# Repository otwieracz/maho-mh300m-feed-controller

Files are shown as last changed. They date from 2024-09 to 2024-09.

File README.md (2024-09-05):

# MAHO MH300M Feedrate Controller

## 1. Introduction

### 1.1 Purpose

The MH300M Feedrate Controller is designed to precisely align the panel readings for feed control on the MAHO MH300M milling machine with the voltage output for the tachogenerator. This ensures that the machine operates with accurate and reliable feed rates after the original BBbC LE 10 b-E driver was replaced with a Parker 512C driver.

### 1.2 Overview

This device is retrofitted into the control box of the MAHO MH300M, requiring no changes to the existing wiring. It connects to the Parker 512C driver, the machine's potentiometer, and the control panel's RAPID and CREEP (1/100) buttons. The device converts arbitrary potentiometer values into a calibrated voltage output, ensuring that the machine's feed rates are consistent and accurate.

### 1.3 MAHO MH300M Control Panel

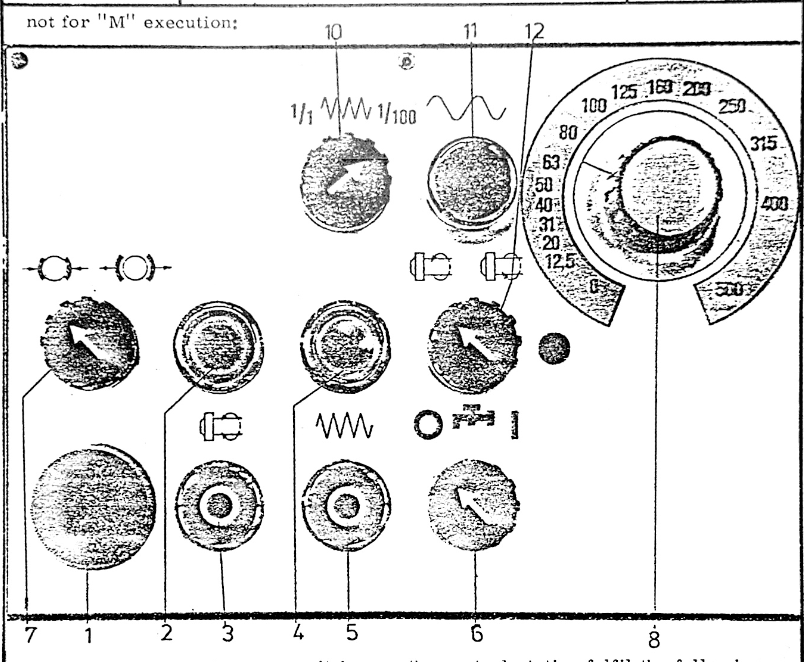
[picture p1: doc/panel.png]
MH300M Control panel


10. Creep feed rate switch (1/1 - 1/100). *Note: MAHO MH300M Feedrate Controller reduces the feed rate by a factor of 10 instead of 100 when in Creep Mode.*
11. Rapid feed rate switch.
12. Feedrate potentiometer.

## 2. Device Components and Connections

### 2.1 Connectors

The device has the following connectors:

- **512C Connector**: 
  - +10V Reference (maximum 5mA)
  - Analog Setpoint (output from the device)
  - Ground (GND)
- **Potentiometer Connector**: Connects to the machine's potentiometer.
- **RAPID and CREEP Button Connectors**: Connects to the control panel's RAPID and CREEP (1/100) buttons.
- **Clear EEPROM Button**: Used to reset the device's configuration stored in EEPROM.

### 2.2 LED Indicator

The device includes an LED indicator used to convey various status messages during setup and operation. The LED blinks in specific patterns to communicate different messages.

## 3. Configuration and Calibration

### 3.1 Initial Setup

Upon installation, the device requires calibration to match the feed rates of the milling machine with the appropriate voltage output. This calibration process is stored in the device's EEPROM, ensuring that the settings persist even after power cycles.

### 3.2 Clearing EEPROM

If you need to reset the device to its default configuration, press and hold the **Clear EEPROM** button while powering on the device. This will erase all stored settings and reset the device to its factory state.

**Note:** Clearing the EEPROM will require recalibration.

### 3.3 Calibration Procedures

Calibration is done in two main steps: configuring the digital potentiometer and setting the ADC steps.

#### 3.3.1 Digital Potentiometer Calibration

1. **Minimum Feed Rate Calibration**: 
   - The **Minimum Feed Rate** is the lowest feed rate at which the milling machine can operate stably. This feed rate is crucial as it ensures that the machine can perform slow movements without stalling, particularly under heavy loads.
   - To accurately determine the minimum feed rate, it's recommended to run all axes simultaneously, especially the Z-axis moving upward, as this simulates the heaviest load.
   - The device will enter the calibration mode for the minimum feed rate (in mm/min).
   - The LED will blink a long-short pattern (`-.`).
   - The device reads the analog input for 30 seconds to determine the minimum digital potentiometer value necessary to maintain stable operation.

2. **500 mm/min Feed Rate Calibration**:
   - The 500 mm/min feed rate serves as a key reference point. This feed rate corresponds to a voltage output of **4.16V** at the terminals of the Parker 512C.
   - The LED will blink a short-long pattern (`.-`).
   - To accurately measure this, connect a voltmeter to the 512C terminals to account for any voltage drop between the control box and the driver.
   - The device adjusts the potentiometer until the voltmeter reads exactly 4.16V, ensuring that the machine's feed rate is precisely 500 mm/min.

#### 3.3.2 ADC Steps Calibration

The device divides the feed rate range into 16 steps, each representing a specific feed rate.

1. **Step Calibration**:
   - For each step, the device reads the analog input for 5.5 seconds.
   - The LED will blink a long-long pattern (`--`) during each step.
   - For each step, set the potentiometer `10` on control panel to the corresponding feed rate (0, 12.5, 20, 31, 40, 50, 63, 80, 100, 125, 160, 200, 250, 315, 400, 500 mm/min).
   - The device will automatically store the ADC value corresponding to each feed rate in the EEPROM.

#### 3.3.3 EEPROM Storage

Once calibration is complete, the device will store the configuration in EEPROM, indicated by two short blinks (`..`). The device will then use this configuration to convert potentiometer values into the appropriate voltage output.

### 3.4 Manual Calibration and Monitoring via UART

#### 3.4.1 Overview

The UART interface is the primary method for monitoring and configuring the MH300M Feedrate Controller. This interface allows you to observe real-time status messages during the calibration process and verify the configuration settings. You can use any UART-capable device, such as a USB-to-UART adapter or a device like the Flipper Zero, to connect to the controller and monitor the serial output.

#### 3.4.2 Setting Up UART Communication

To begin using UART communication:

1. **Connect the Device**:
   - Connect the device's UART pins to your computer using a USB-to-UART adapter or to a handheld UART interface like the Flipper Zero.
   - Ensure the connection uses the correct UART pins (TX, RX, GND).

2. **Open a Serial Terminal**:
   - Open a serial terminal program on your computer (such as PuTTY, Tera Term, or the Arduino IDE's Serial Monitor).
   - Set the baud rate to **9600**.
   - Configure the terminal for **8 data bits, no parity, and 1 stop bit** (8N1).

3. **Start the Device**:
   - Power on the device. The serial terminal will begin displaying messages as the device goes through its initialization and calibration process.

#### 3.4.3 Calibration Process and UART Messages

The calibration process involves several steps, each of which is communicated via the UART interface. Below is a detailed breakdown of the calibration process, along with the messages you will see in the UART terminal.

1. **Initialization**:
   - **Starting Message**:
     - **UART Message**: `starting`
     - Description: Indicates that the device has powered on and is beginning the setup process.
   - **Button Setup**:
     - **UART Message**: `setting up buttons`
     - Description: The device configures the input pins for the RAPID, CREEP, and CLEAR EEPROM buttons.

2. **Configuration Reading**:
   - **Valid Configuration**:
     - **UART Message**: `valid config`
     - Description: Indicates that the device successfully read a valid configuration from the EEPROM.
   - **Invalid Configuration**:
     - **UART Message**: `invalid configuration`
     - Description: The configuration in the EEPROM is either missing or corrupt, triggering the initialization of a new calibration process.

3. **Calibration Steps**:
   - **Digital Potentiometer Minimum Calibration**:
     - **UART Message**: `initializing configuration`
     - Description: The device begins the calibration process.
     - **UART Message**: `config.digipot_min: <value>`
     - Description: The device determines and displays the minimum digital potentiometer value required for stable operation.
   - **Digital Potentiometer 500 mm/min Calibration**:
     - **UART Message**: `config.digipot_500: <value>`
     - Description: The device calculates and displays the digital potentiometer value corresponding to a 500 mm/min feed rate.
   - **ADC Setpoint Calibration**:
     - **UART Message**: `config.feed_<feed_rate>: <adc_value>`
     - Description: For each step in the feed rate table, the device reads and displays the corresponding ADC value. This process repeats for each of the 16 predefined steps.
   - **Completion Message**:
     - **UART Message**: `initialization complete`
     - Description: Indicates that the calibration process has finished successfully, and the configuration has been stored in the EEPROM.

#### 3.4.4 Operation Monitoring via UART

During normal operation, the UART interface continues to output real-time status messages, allowing you to monitor the device's performance:

- **Feed Rate and Voltage Output**:
  - **UART Message**: `fr: <feedrate>mm/min / <voltage>V`
  - Description: Displays the current feed rate in mm/min and the corresponding voltage output to the Parker 512C.

#### 3.4.5 Troubleshooting via UART

Use the UART messages to diagnose issues:

- If the device repeatedly outputs `invalid configuration`, ensure that the EEPROM is not corrupted or repeatedly reset.
- Monitor the feed rate and voltage messages to verify that the device operates as expected under different conditions (e.g., with RAPID or CREEP buttons pressed).

### 3.4.6 Flowchart of the Calibration Process with UART Monitoring

```mermaid
graph TD
    A[Power On] --> B{Clear EEPROM Button Pressed?}
    B -- Yes --> C[Clear EEPROM and Reset Configuration]
    B -- No --> D[Read Configuration from EEPROM]
    D -- Invalid --> E[Initialize Calibration]
    E --> F[Calibrate Digipot Min]
    F --> G[Calibrate Digipot 500 mm/min]
    G --> H[Calibrate ADC Setpoints]
    H --> I[Save Configuration to EEPROM]
    D -- Valid --> J[Start Operation]
    I --> J
    J --> K[Monitor Potentiometer Values]
    K --> L[Calculate Feedrate]
    L --> M[Convert Feedrate to Digipot Value]
    M --> N[Output Voltage to 512C]
```
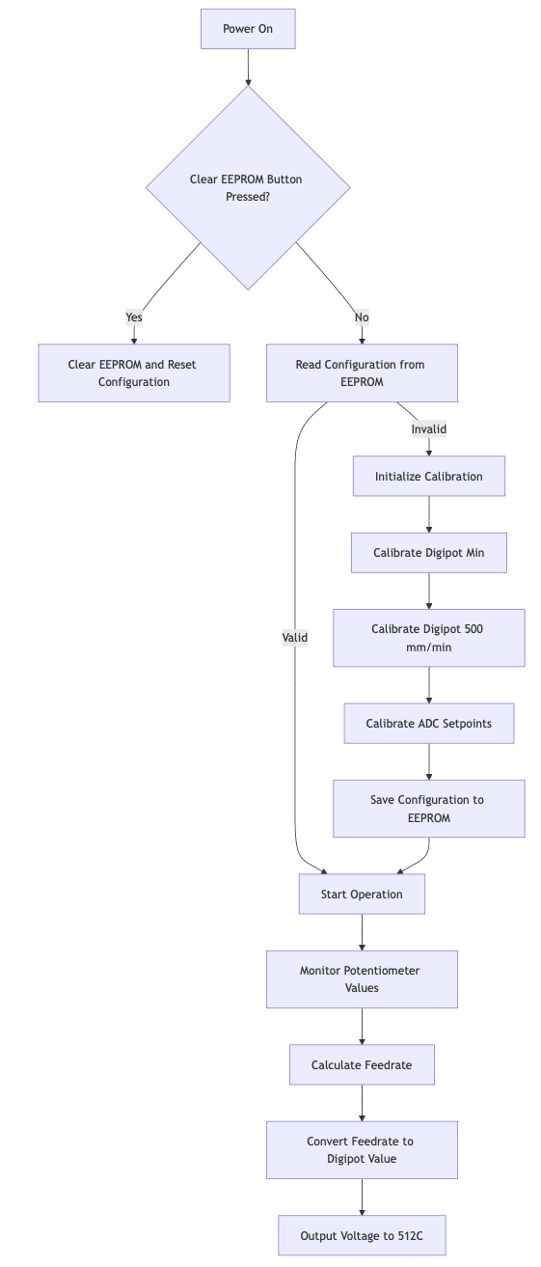
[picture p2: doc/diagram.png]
diagram


## 4. Operation

### 4.1 Normal Operation

Once configured, the device operates automatically, continuously converting the potentiometer's analog signal into a precise voltage output that drives the tachogenerator. This output is based on the calibrated settings stored in EEPROM.

### 4.2 Button Functions

- **RAPID Button**: When pressed, the feed rate is set to 1200 mm/min, overriding the potentiometer setting.
- **CREEP Button**: When pressed, the feed rate is reduced by a factor of 10.

### 4.3 Power Saving Mode

The device enters a low-power state between readings to conserve energy. This does not affect the device's performance but ensures it operates efficiently.

## 5. Maintenance and Troubleshooting

### 5.1 Regular Maintenance

The device requires minimal maintenance. Periodically check the connectors and wiring to ensure they are secure and free of damage.

### 5.2 Troubleshooting

- **No Output Voltage**: Verify that the device is receiving power and that the potentiometer is functioning correctly.
- **Incorrect Feed Rate**: Re-run the calibration procedure to ensure the settings are accurate.
- **LED Indicator Not Blinking**: Check the LED connections and ensure the device is powered on.

## 6. Technical Specifications

- **Input Voltage**: 10V from the Parker 512C
- **Analog Setpoint Output Range**: 0-10V
- **Maximum Current Draw**: 5mA from the 10V reference
- **EEPROM Storage**: Non-volatile memory storing calibration settings
- **Power Saving Mode**: Automatic, with 250ms sleep cycles

## 7. Safety Information

- Ensure all connections are secure before powering on the device.
- Do not attempt to modify the device's hardware.
- Use the device only for its intended purpose with the MAHO MH300M milling machine.

## Chapter 8: Programming the MH300M Feedrate Controller

### 8.1 Overview

Programming the MH300M Feedrate Controller involves configuring the microcontroller, setting fuse bits, and uploading the firmware. This chapter provides general guidelines on how to perform these tasks using standard AVR/Arduino practices.

### 8.2 Fuse Settings

Fuse settings are crucial for defining how the microcontroller operates at a hardware level. The fuses should be set to ensure the following:

- **Clock Source**: The microcontroller should use the internal oscillator with a specific clock divider to achieve the desired operating frequency (e.g., 1 MHz).
- **Bootloader Settings**: The fuses should be configured to allow the microcontroller to use a bootloader, if applicable.
- **EEPROM Retention**: Ensure that the EEPROM data is preserved during a chip erase.
- **Brown-Out Detection**: Configure the Brown-Out Detection (BOD) settings according to the requirements, or disable it if not needed.

These settings are typically configured using low, high, and extended fuse bits. Proper fuse settings ensure that the device runs at the correct speed, retains necessary data, and operates reliably under different power conditions.

### 8.3 Build Configuration

When building the firmware for the MH300M Feedrate Controller, the following flags and settings should be considered:

- **Microcontroller Type**: Ensure that the target microcontroller (e.g., ATmega328P) is correctly specified in the build configuration.
- **CPU Frequency**: Set the CPU frequency to match the hardware configuration (e.g., 1 MHz).
- **Build Flags**: Include any necessary build flags to define specific operational parameters or to include/exclude certain features.
  - For example, you might use a flag to specify that the firmware is built for a specific Arduino variant or to control how certain libraries behave.
- **Libraries**: Ensure all required libraries are included, such as those for low-power management or for controlling peripheral devices like digital potentiometers.

### 8.4 Firmware Upload

The firmware can be uploaded to the microcontroller using either an ISP programmer or via a bootloader using a USB-to-UART converter.

- **ISP Upload**: Use an In-System Programmer (ISP) to directly flash the firmware onto the microcontroller. This method allows for full control, including setting fuse bits.
- **UART Upload**: If using a bootloader, upload the firmware via a USB-to-UART converter. Ensure that the correct upload protocol (e.g., stk500v1) and baud rate (e.g., 9600) are set.

During the upload process, you may need to specify additional flags for the upload tool to correctly communicate with the microcontroller and write the firmware.

### 8.5 Final Steps

After programming:

1. **Verify Fuse Settings**: Ensure that the fuse settings are correctly applied.
2. **Test the Device**: Power on the device and verify basic functionality, such as LED indicators and response to input signals.
3. **Monitor Output**: If applicable, use a UART interface to monitor the device’s startup messages and operational status.

By following these general guidelines, you can ensure that the MH300M Feedrate Controller is programmed correctly and operates as intended.

# Appendix A: Schematics

The following schematics detail the connections and components used in the MH300M Feedrate Controller:

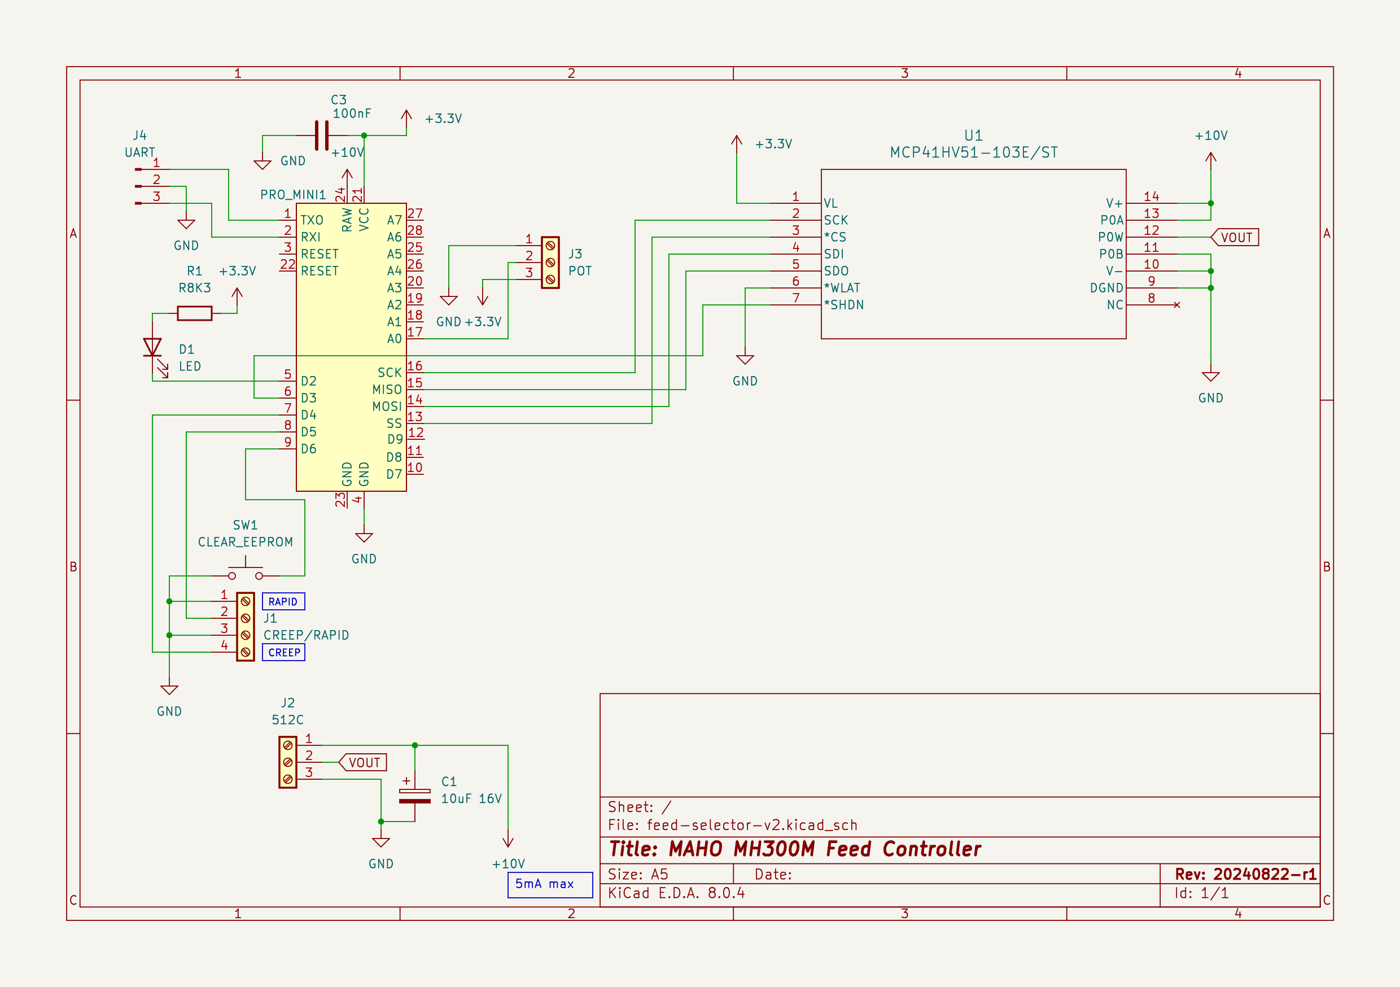
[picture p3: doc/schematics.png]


# Appendinx B: Bill of Materials

|Id |Designator|Footprint |Quantity|Designation |
|---|---|---|---|---|
|1  |C1 |CP_Radial_D4.0mm_P2.00mm |1 |10uF 16V | | | |
|2  |J4 |JST_XH_B3B-XH-A_1x03_P2.50mm_Vertical |1 |UART | | | |
|3  |R1 |R_Axial_DIN0207_L6.3mm_D2.5mm_P7.62mm_Horizontal|1 |R8K3 | | | |
|4  |U1 |TSSOP14_MC_MCH |1 |MCP41HV51-103E/ST| | | |
|5  |J1 |TerminalBlock_bornier-4_P5.08mm |1 |CREEP/RAPID | | | |
|6  |J3 |TerminalBlock_bornier-3_P5.08mm |1 |POT | | | |
|7  |PRO_MINI1 |Arduino_Pro_Mini (3V3, 8MHz) |1 |~ | | | |
|8  |C3 |C_Disc_D5.0mm_W2.5mm_P2.50mm |1 |100nF | | | |
|9  |SW1 |SW_PUSH_6mm |1 |CLEAR_EEPROM | | | |
|10 |J2 |TerminalBlock_bornier-3_P5.08mm |1 |512C | | | |
|11 |D1 |LED_D5.0mm |1 |LED | | | |

# Appendix C: PCB Layout

## Top Layer
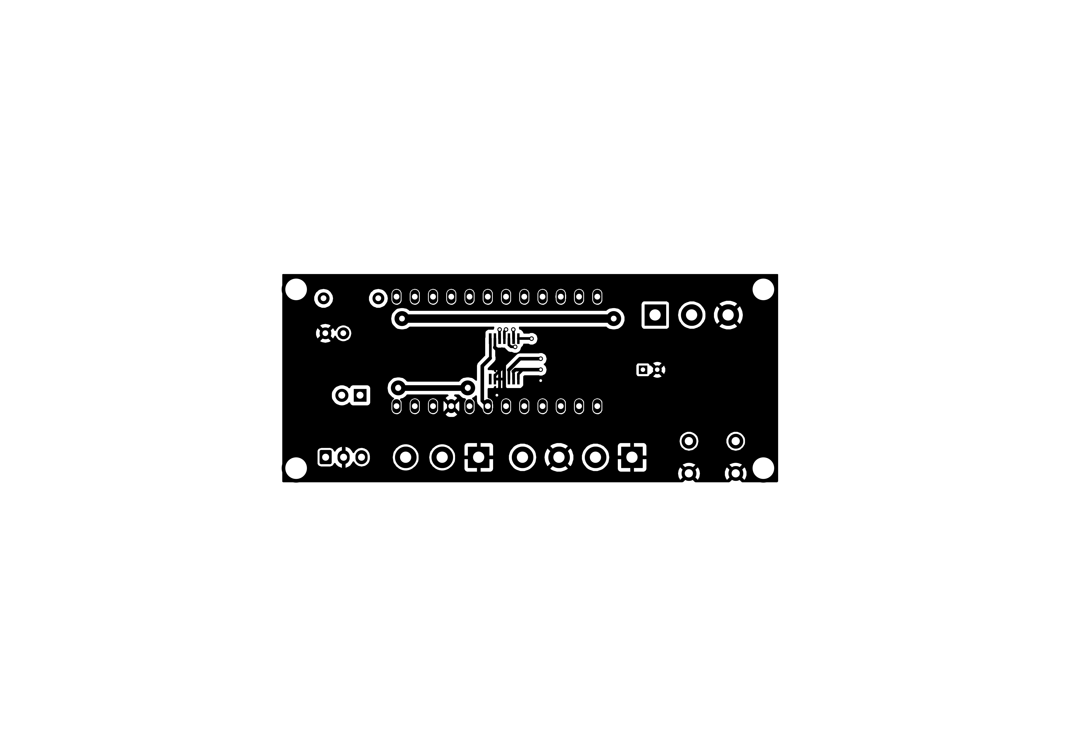
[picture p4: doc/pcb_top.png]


## Bottom Layer
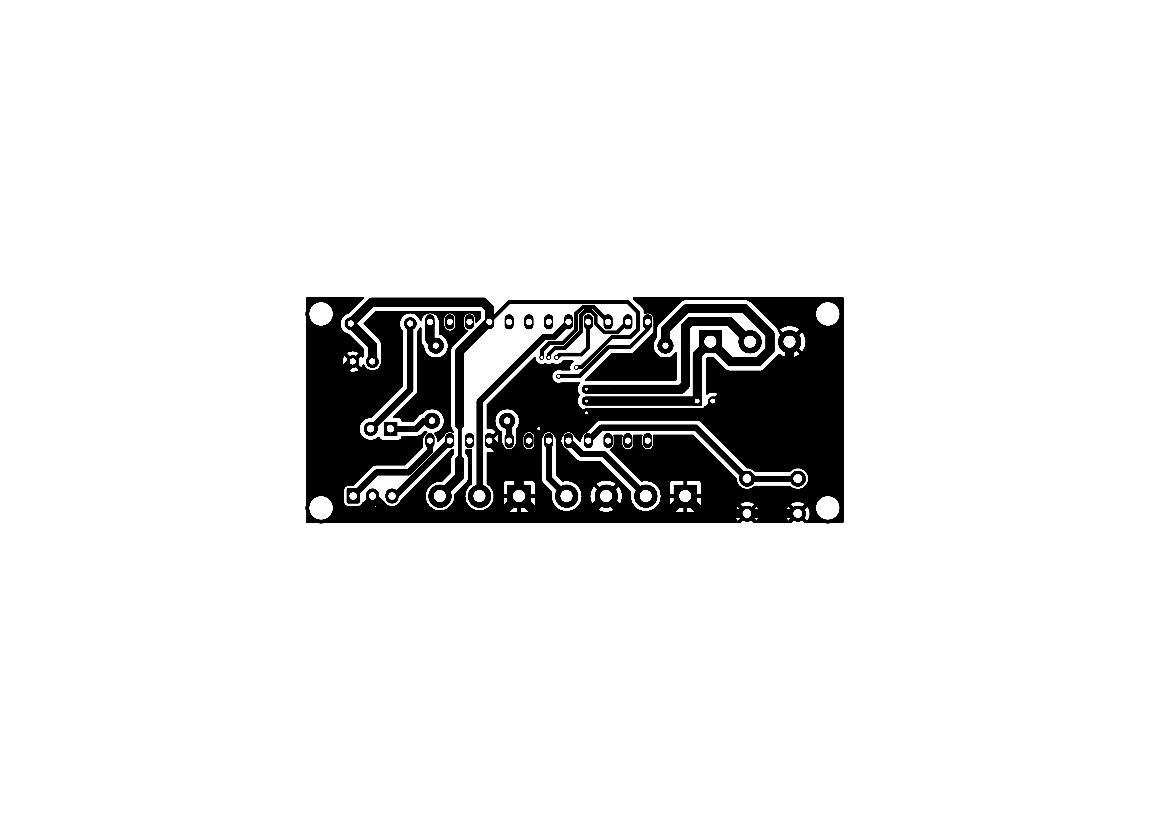
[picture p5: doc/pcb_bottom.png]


# Appendix D: Case sticker

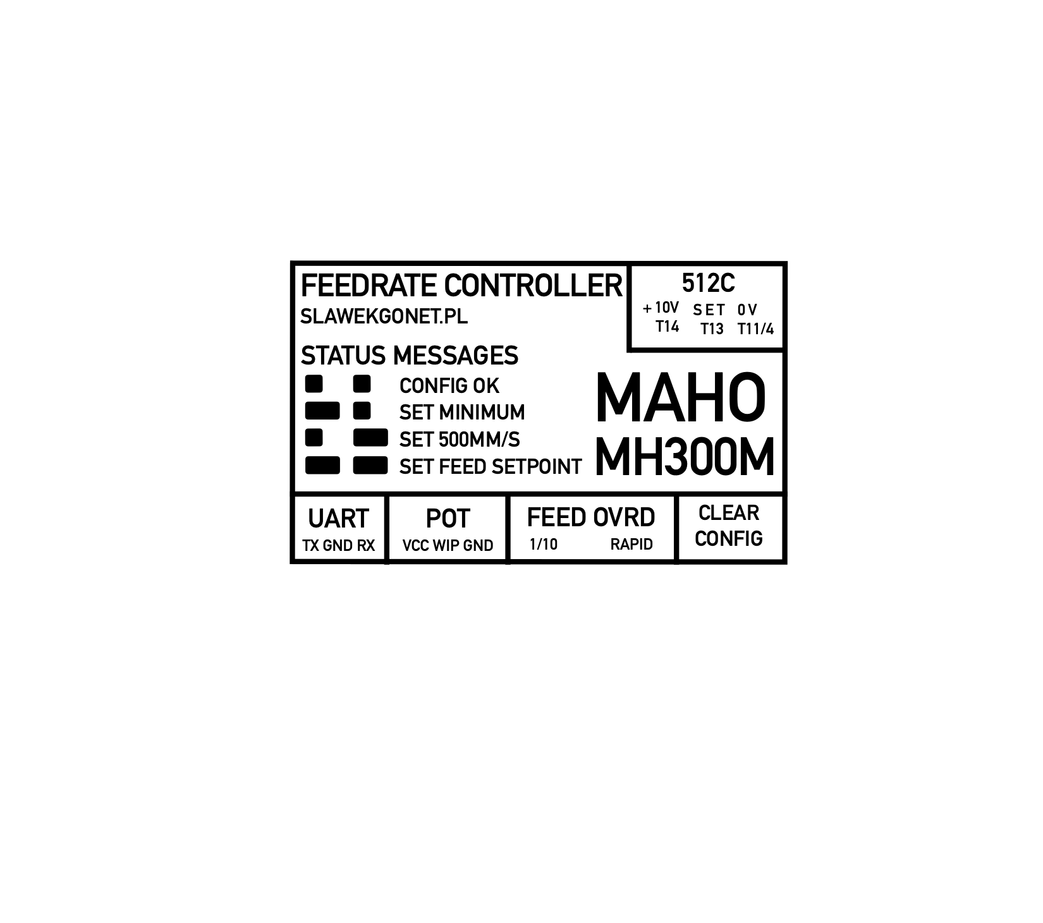
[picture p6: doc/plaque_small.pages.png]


# Appendix E: Firmware Source Code

## `include/blinkmsg.h`
```cpp
#ifndef BLINKMSG_H
#define BLINKMSG_H

enum BLINKMSG {
  BLINKMSG_CONFIG_OK,
  BLINKMSG_SETUP_DIGIPOT_MIN,
  BLINKMSG_SETUP_DIGIPOT_500,
  BLINKMSG_SETUP_ADC_SETPOINT,
};

void blinkmsg(int blinkmsg);
#endif
```

## `include/config.h`
```cpp
// Arduino Mega 2560
#ifdef ARDUINO_AVR_MEGA2560
#define ANALOG_PIN A0
#define RAPID_BTN_PIN 52
#define CREEP_BTN_PIN 53
#define CLEAR_EEPROM_BTN_PIN 51
#define CS_PIN 10
#define SHDN_PIN 54
#define LED_PIN 55
#endif

// Arduino Pro Mini 3.3V 8MHz
#ifdef ARDUINO_AVR_PRO
#define ANALOG_PIN A0
#define RAPID_BTN_PIN 5
#define CREEP_BTN_PIN 4
#define CLEAR_EEPROM_BTN_PIN 9
#define CS_PIN 10
// #define SHDN_PIN 6
// #define LED_PIN 5
#define SHDN_PIN 3
#define LED_PIN 2
#endif
```

## `src/main.cpp`
```cpp
#include <Arduino.h>
#include <EEPROM.h>
#include <LowPower.h>
#include <MCP41HVX1.h>
#include <SPI.h>
#include <blinkmsg.h>
#include <config.h>

MCP41HVX1 digipot(CS_PIN, SHDN_PIN, MCP41HVX1_PIN_NOT_CONFIGURED);

#define ADC_MAX 1023
#define DIGIPOT_MAX 255

#define N_STEPS 16    // Number of steps in the conversion table
#define RAPID 1200    // Rapid feed rate in mm/min
#define CREEP_DIV 10  // Creep feed rate divisor

#define CONFIG_VERSION 2
struct EepromConfig {
  int version;
  int digipot_min;  // Minimum digipot value for stable feed rate (15bit)
  int digipot_500;  // digipot value for 500mm/min feed rate - 4.16V measured at
                    // controller (15bit)
  int adc_setpoint[N_STEPS];  // ADC setpoint for each step in the conversion
                              // table
};

// ADC setpoints (feed rate) for each step in the conversion table
// note: 12mm/min is used instead of 12.5mm/min to avoid floating point
// arithmetic
int feed_table[N_STEPS] = {0,   12,  20,  31,  40,  50,  63,  80,
                           100, 125, 160, 200, 250, 315, 400, 500};

// Config - unititialized, to be read from EEPROM
EepromConfig config;

//
// Setup functions
//

// Reset configuration
void reset_eeprom_config(int addr) {
  EepromConfig default_config = {
      .version = 0, .digipot_min = 0, .digipot_500 = 0, .adc_setpoint = {0}};
  EEPROM.put(addr, default_config);
}

// Read config from EEPROM
bool read_config(EepromConfig *config) {
  int addr = 0;

  // Reset configuration if CLEAR_EEPROM button is pressed
  if (digitalRead(CLEAR_EEPROM_BTN_PIN) == LOW) {
    Serial.println("resetting configuration");
    reset_eeprom_config(addr);
    return false;
  }

  EepromConfig eeprom_config;
  EEPROM.get(addr, eeprom_config);
  if (eeprom_config.version == CONFIG_VERSION) {
    Serial.println("valid config");
    blinkmsg(BLINKMSG_CONFIG_OK);
    *config = eeprom_config;
    return true;
  } else {
    Serial.println("invalid configuration");
    return false;
  }
}

// Write empty config to EEPROM with version 0, enforcing reinitialization
void reset_eeprom_config() {
  EepromConfig default_config = {
      .version = 0, .digipot_min = 0, .digipot_500 = 0, .adc_setpoint = {0}};
  EEPROM.put(0, default_config);
}

// Setup buttons
void setup_buttons() {
  Serial.println("setting up buttons");
  pinMode(RAPID_BTN_PIN, INPUT_PULLUP);
  pinMode(CREEP_BTN_PIN, INPUT_PULLUP);
  pinMode(CLEAR_EEPROM_BTN_PIN, INPUT_PULLUP);
  pinMode(LED_PIN, OUTPUT);
  digitalWrite(LED_PIN, HIGH);
}

//
// Calibration procedures
//

// Calibrate digital potentionmeter
int calibrate_digipot(const char *name, unsigned int wait_time) {
  Serial.print("config.");
  Serial.print(name);
  Serial.print(": ");
  Serial.flush();

  // Keep reading the analog input for wait_time ms
  unsigned long start = millis();
  int digipot_out = 0;
  while (millis() - start < wait_time) {
    int adc_in = analogRead(ANALOG_PIN);
    digipot_out = map(adc_in, 0, ADC_MAX, 0, DIGIPOT_MAX);
    digipot.WiperSetPosition(digipot_out);
    delay(100);
  }

  Serial.println(digipot_out);

  return digipot_out;
}

// Calibrate ADC steps
//
void calibrate_adc_step(unsigned int step, int *buf, unsigned int wait_time) {
  int feed = feed_table[step];

  Serial.print("config.feed_");
  Serial.print(feed);
  Serial.print(": ");

  // Keep reading the analog input for wait_time ms
  unsigned long start = millis();
  int adc_in = 0;
  while (millis() - start < wait_time) {
    adc_in = analogRead(ANALOG_PIN);
    delay(100);
  }

  buf[step] = adc_in;

  Serial.println(adc_in);
}

void initialize_config() {
  Serial.println("initializing configuration");
  blinkmsg(BLINKMSG_SETUP_DIGIPOT_MIN);
  int digipot_min = calibrate_digipot("digipot_min", 30000);
  blinkmsg(BLINKMSG_SETUP_DIGIPOT_500);
  int digipot_500 = calibrate_digipot("digipot_500", 30000);

  EepromConfig new_config = {.version = CONFIG_VERSION,
                             .digipot_min = digipot_min,
                             .digipot_500 = digipot_500,
                             .adc_setpoint = {0}};

  for (int i = 0; i < N_STEPS; i++) {
    blinkmsg(BLINKMSG_SETUP_ADC_SETPOINT);
    calibrate_adc_step(i, new_config.adc_setpoint, 5500);
  }

  blinkmsg(BLINKMSG_CONFIG_OK);
  EEPROM.put(0, new_config);
}

// Value mapping
//

// For given ADC input range, return the id of the lower bound
// of the range that contains the value
int find_range(int adc_value) {
  // Example:
  // adc_setpoint = {0, 100, 200, 300}
  // adc_value = 150
  // [1]:100 < adc_value:150 <= [2]:200
  // return 1

  for (int i = 0; i < N_STEPS - 1; i++) {
    if (config.adc_setpoint[i] < adc_value &&
        adc_value <= config.adc_setpoint[i + 1]) {
      return i;
    }
  }
  return 0;
}

// For given ADC value, return the feedrate in mm/min
// based on the conversion table and the current setpoint
// and the state of the rapid and creep buttons
int feedrate() {
  int adc_value = analogRead(ANALOG_PIN);
  int range_id = find_range(adc_value);

  bool rapid = digitalRead(RAPID_BTN_PIN) == LOW;
  bool creep = digitalRead(CREEP_BTN_PIN) == LOW;

  int feedrate = 0;

  if (rapid) {
    feedrate = RAPID;
  } else if (adc_value < config.adc_setpoint[1]) {
    /* Round adc values for feeds lower than 12mm/min (between 0 and first step)
     * to 0 to avoid feedrate oscillation */
    feedrate = 0;
  } else if (adc_value == 0) {
    feedrate = 0;
  } else {
    feedrate = map(adc_value, config.adc_setpoint[range_id],
                   config.adc_setpoint[range_id + 1], feed_table[range_id],
                   feed_table[range_id + 1]);
  }

  if (creep && !rapid) {
    feedrate = feedrate / CREEP_DIV;
  }
  return feedrate;
}

// Convert feedrate in mm/min to digipot value
// based on the current configuration
// If reported feedrate is non-zero, but the calculated digipot value is below
// the minimum, return the minimum digipot value to ensure stable operation
long int feedrate_to_digipot(int feedrate) {
  long feed_digipot = (long)feedrate * (long)config.digipot_500 / 500;

  if (feedrate == 0) {
    return 0;
  } else if (feed_digipot > DIGIPOT_MAX) {
    return DIGIPOT_MAX;
  } else if (feed_digipot > 0 && feed_digipot < config.digipot_min) {
    return config.digipot_min;
  } else {
    return feed_digipot;
  }
}

bool setup_complete = false;

void setup() {
  Serial.begin(9600);
  Serial.println("starting");
  Serial.flush();
  setup_buttons();

  if (!read_config(&config)) {
    initialize_config();
    read_config(&config);
  }

  Serial.flush();
}

void loop() {
  int feedrate_val = feedrate();
  long int digipot_value = feedrate_to_digipot(feedrate_val);
  long int mv = map(digipot_value, 0, DIGIPOT_MAX, 0, 10000);

  if (digipot_value > 0) {
    digipot.ResistorNetworkEnable();
    digipot.WiperSetPosition(digipot_value);
  } else {
    digipot.ResistorNetworkDisable();
  }

  int v = mv / 1000;
  int v_mod = mv % 1000;
  char buf[64];
  sprintf(buf, "fr: %4dmm/min / %1d.%02dV", feedrate_val, v, v_mod / 10);
  Serial.println(buf);
  Serial.flush();

  LowPower.powerDown(SLEEP_250MS, ADC_OFF, BOD_OFF);
}
```

## `src/blinkmsg.cpp`
```cpp
#include <Arduino.h>
#include <blinkmsg.h>
#include <config.h>

#define MESSAGE_LENGTH 1000
#define MESSAGE_SHORT 100
#define MESSAGE_LONG 700

//
// LED messages
//

void blink_led(const char *msg) {
  for (int i = 0; i < 2; i++) {
    if (msg[i] == '.') {
      digitalWrite(LED_PIN, LOW);
      delay(MESSAGE_SHORT);
      digitalWrite(LED_PIN, HIGH);
      delay(MESSAGE_LENGTH - MESSAGE_SHORT);
    } else if (msg[i] == '-') {
      digitalWrite(LED_PIN, LOW);
      delay(MESSAGE_LONG);
      digitalWrite(LED_PIN, HIGH);
      delay(MESSAGE_LENGTH - MESSAGE_LONG);
    }
  }
}

void blinkmsg(int blinkmsg) {
  switch (blinkmsg) {
    case BLINKMSG_CONFIG_OK:
      blink_led("..");
      break;
    case BLINKMSG_SETUP_DIGIPOT_MIN:
      blink_led("-.");
      break;
    case BLINKMSG_SETUP_DIGIPOT_500:
      blink_led(".-");
      break;
    case BLINKMSG_SETUP_ADC_SETPOINT:
      blink_led("--");
      break;
  }
}
```

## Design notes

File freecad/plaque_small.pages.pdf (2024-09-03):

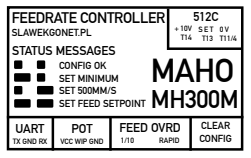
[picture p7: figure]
MAHO MH300M; FEEDRATE CONTROLLER; STATUS MESSAGES CONFIG OK SET MINIMUM SET 500MM/S SET FEED SETPOINT; SLAWEKGONET.PL; SET T13; UART; TX GND RX; POT; VCC WIP GND; FEED OVRD; RAPID; CLEAR CONFIG

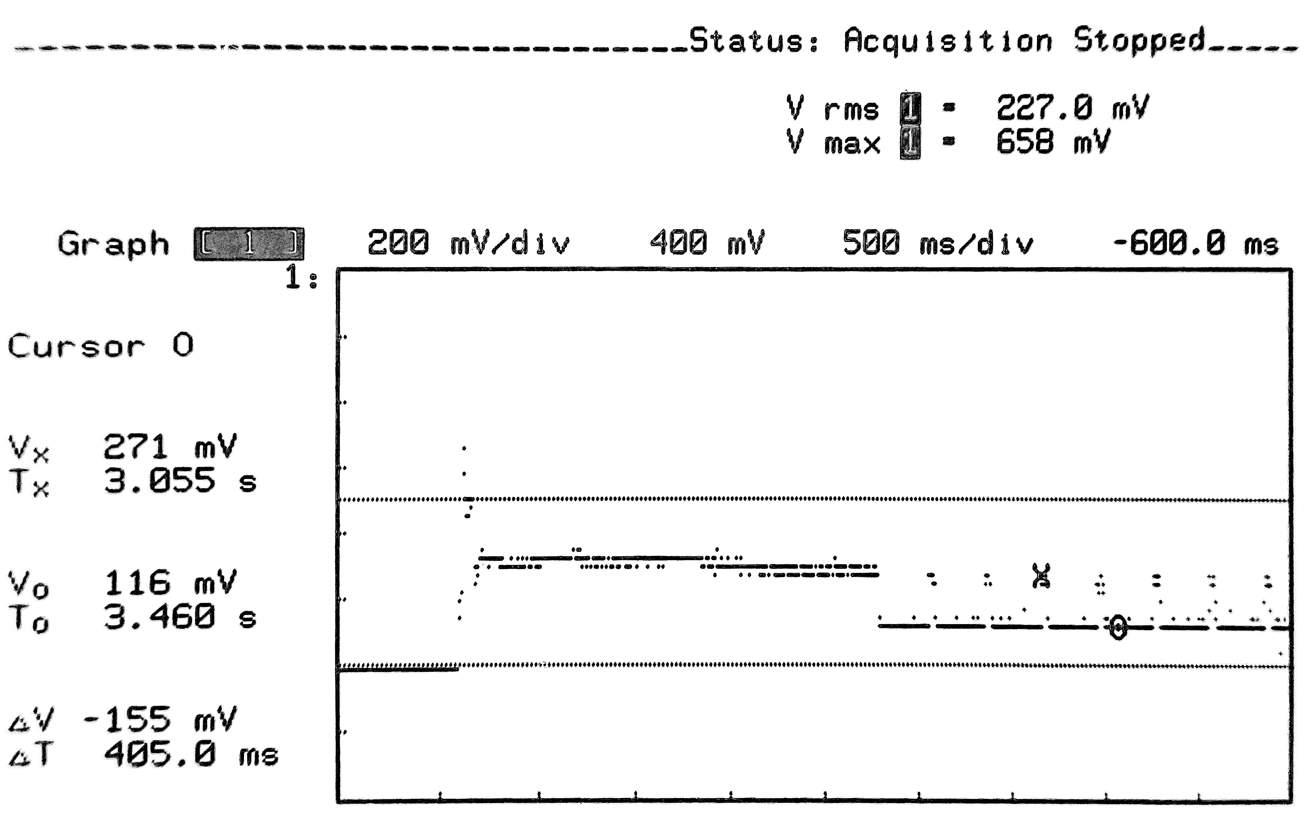
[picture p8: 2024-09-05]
doc/current.png

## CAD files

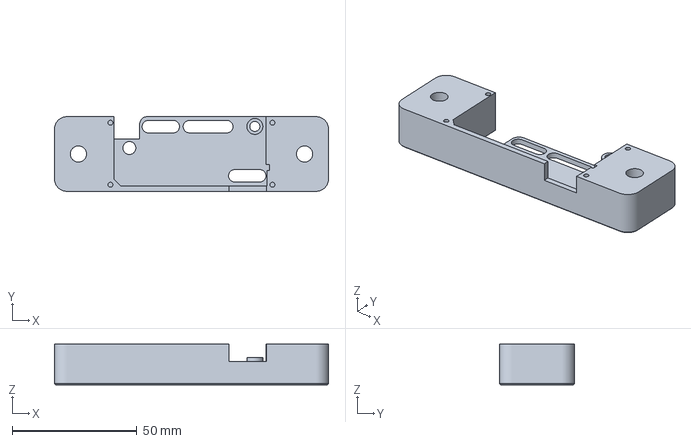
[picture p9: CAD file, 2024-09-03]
freecad/P_feed-selector-v2-top.3mf
110.0 x 30.0 x 16.4 mm

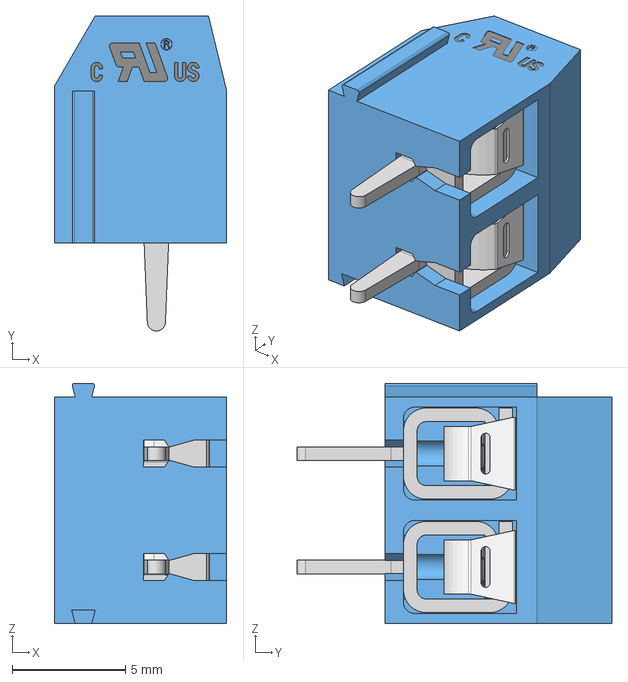
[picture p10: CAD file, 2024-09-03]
kicad/2 PIN - DG306-5 - PITCH 5 mm.stp
7.60 x 13.9 x 10.6 mm

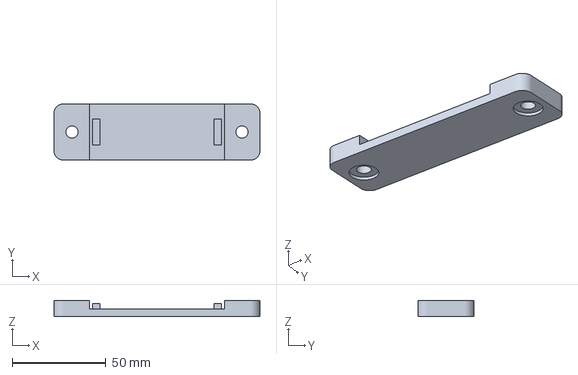
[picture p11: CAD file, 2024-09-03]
kicad/feed-selector-v2-bottom.3mf
110.0 x 30.0 x 8.60 mm

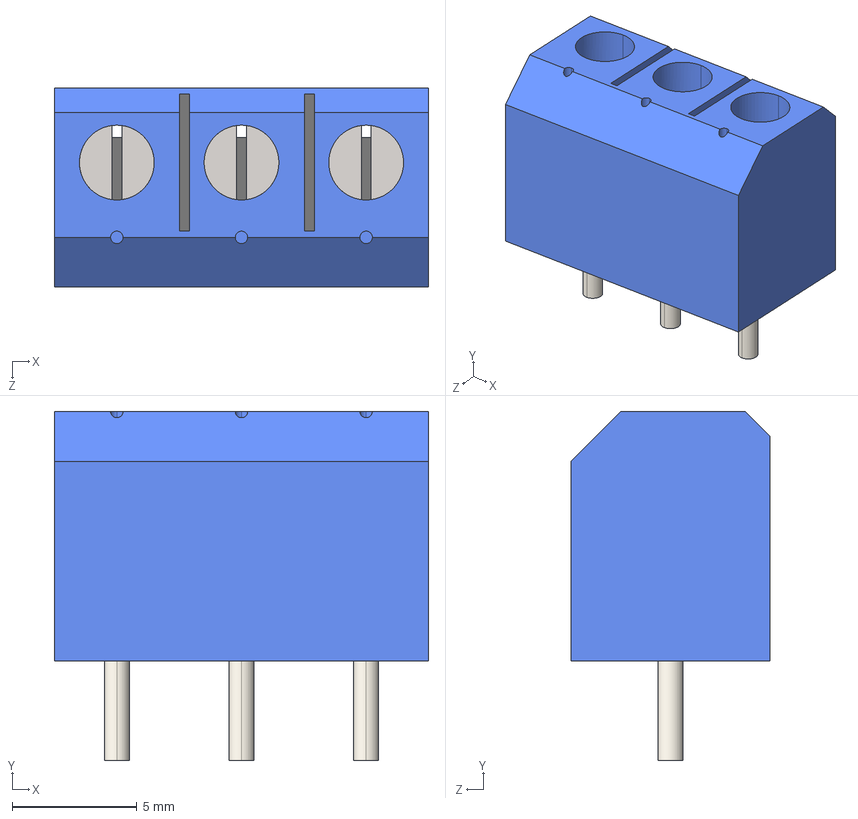
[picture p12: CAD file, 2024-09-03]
kicad/bornera de 3 terminales v2.0.STEP
15.0 x 14.0 x 8.00 mm

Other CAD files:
kicad/feed-selector-v2-top.3mf

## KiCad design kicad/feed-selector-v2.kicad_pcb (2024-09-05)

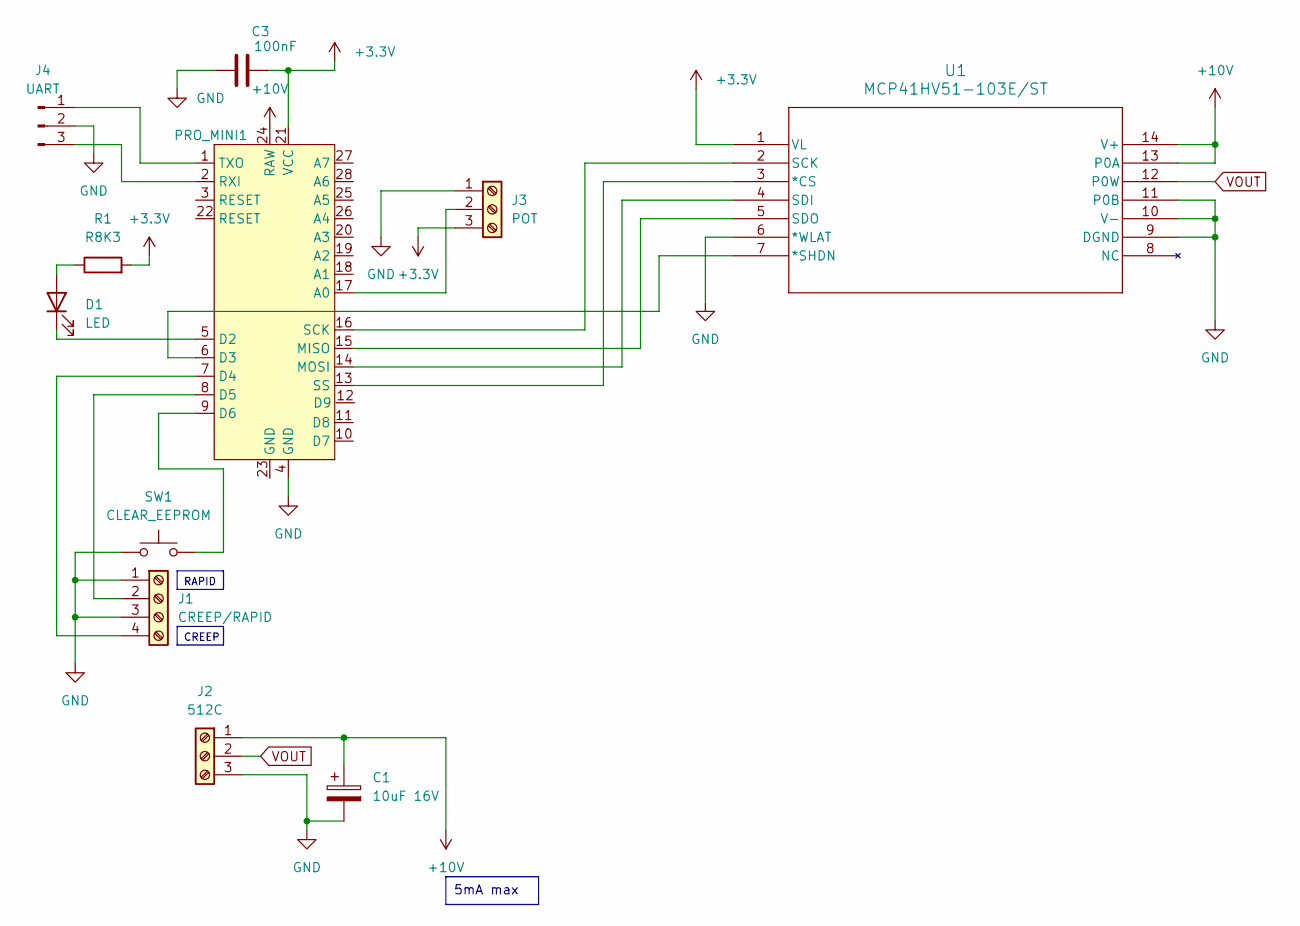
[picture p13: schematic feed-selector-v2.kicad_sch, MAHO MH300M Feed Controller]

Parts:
C1: 10uF 16V; CP_Radial_D4.0mm_P2.00mm
C3: 100nF; C_Disc_D5.0mm_W2.5mm_P2.50mm
D1: LED; LED_D5.0mm
J1: CREEP/RAPID; TerminalBlock_bornier-4_P5.08mm
J2: 512C; TerminalBlock_bornier-3_P5.08mm
J3: POT; TerminalBlock_bornier-3_P5.08mm
J4: UART; JST_XH_B3B-XH-A_1x03_P2.50mm_Vertical
PRO_MINI1: Arduino_Pro_Mini
R1: R8K3; R_Axial_DIN0207_L6.3mm_D2.5mm_P7.62mm_Horizontal
SW1: CLEAR_EEPROM; SW_PUSH_6mm
U1: MCP41HV51-103E/ST; TSSOP14_MC_MCH

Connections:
+3.3V: C3.2, J3.3, PRO_MINI1.21 (VCC), R1.2, U1.1 (VL)
+10V: C1.1, J2.1, PRO_MINI1.24 (RAW), U1.13 (P0A), U1.14 (V+)
GND: C1.2, C3.1, J1.1, J1.3, J2.3, J3.1, J4.2, PRO_MINI1.4 (GND), SW1.1, U1.6 (*WLAT), U1.9 (DGND), U1.10 (V-), U1.11 (P0B)
unnamed: D1.2 (A), R1.1
unnamed: D1.1 (K), PRO_MINI1.5 (D2)
unnamed: J1.2, PRO_MINI1.8 (D5)
unnamed: J1.4, PRO_MINI1.7 (D4)
unnamed: J3.2, PRO_MINI1.17 (A0)
unnamed: J4.1, PRO_MINI1.1 (TXO)
unnamed: J4.3, PRO_MINI1.2 (RXI)
unnamed: PRO_MINI1.6 (D3), U1.7 (*SHDN)
unnamed: PRO_MINI1.9 (D6), SW1.2
unnamed: PRO_MINI1.13 (SS), U1.3 (*CS)
unnamed: PRO_MINI1.14 (MOSI), U1.4 (SDI)
unnamed: PRO_MINI1.15 (MISO), U1.5 (SDO)
unnamed: PRO_MINI1.16 (SCK), U1.2 (SCK)
VOUT: J2.2, U1.12 (P0W)

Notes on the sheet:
RAPID
CREEP
5mA max

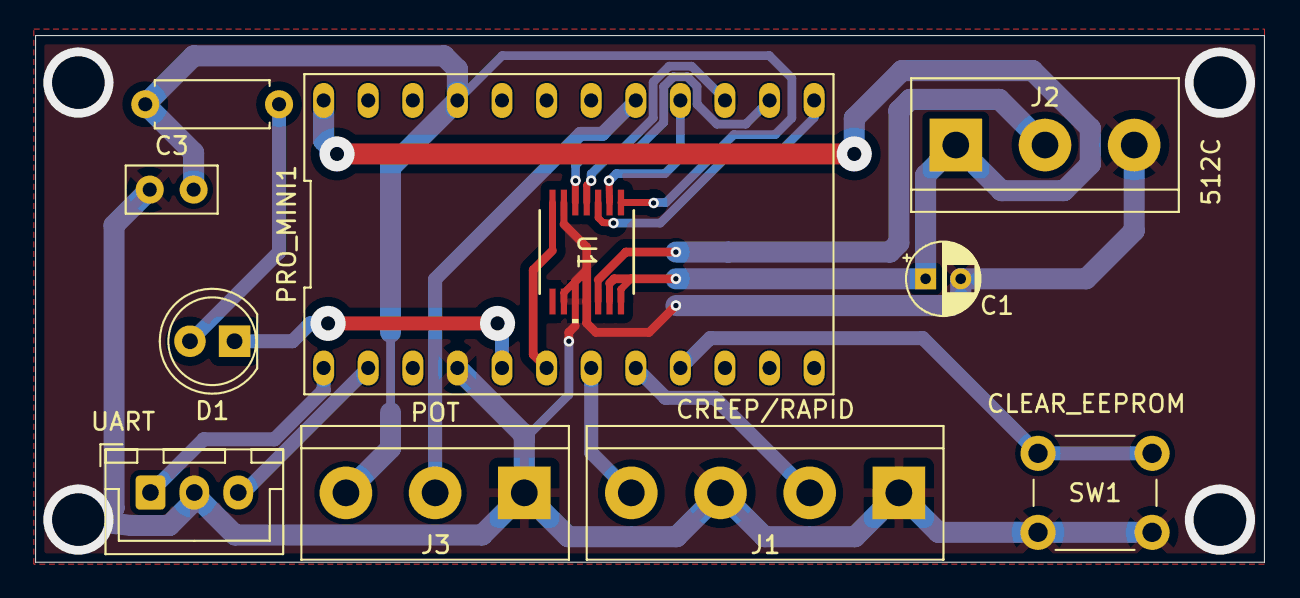
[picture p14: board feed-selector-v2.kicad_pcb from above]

Board: 2 copper layers, 70.0 x 30.0 mm, 11 parts (0 on the bottom side), 17 nets.

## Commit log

2024-06-24 complete calibration
2024-06-25 adc -> feerate conversion
2024-07-14 Switch to 1MHz, internal oscillator
    [blinkmsg.cpp, main.cpp]
2024-09-03 all issues fixed
    [2 PIN - DG306-5 - PITCH 5 mm.stp, P_feed-selector-v2-top.3mf, bornera de 3 terminales v2.0.STEP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]
